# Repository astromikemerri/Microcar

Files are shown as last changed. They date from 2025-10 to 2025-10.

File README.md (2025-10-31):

# Microcar
Project for a tiny remote-control car, driven using linear actuators via a magnet, using phone as steering wheel and accelerator.  Really just having fun with some simple electronics, a 3D printer and ChatGPT to do most of the coding.  



And <A href=https://github.com/astromikemerri/Microcar/blob/main/Testdrive.mov>here is a longer test drive demo</a> to show the full silliness of the project.

In addition to standard accessories like a half-size breadboard and plenty of jumper wires, the hardware that you need, together with some suggested links for buying it, is:
<table>
  <thead> 
    <tr>
      <th>#</th>
      <th>Component</th>
      <th>Quantity</th>
      <th>Description</th>
      <th>Link</th>
    </tr>
  </thead>
  <tbody>
    <tr>
      <td>1</td>
      <td>Seeed Studio XIAO ESP32S3</td>
      <td>1</td>
      <td>ESP32 board with built-in WiFi</td>
      <td><a href="https://www.amazon.co.uk/dp/B0BYSB66S5">link</a></td>
    </tr>
    <tr>
      <td>2</td>
      <td>A4988 Stepper Driver Modules</td>
      <td>2</td>
      <td>driver boards for bipolar stepper control</td>
      <td><a href="https://www.amazon.co.uk/dp/B083V59HTB">link</a></td>
    </tr>
    <tr>
      <td>3</td>
      <td>Lead-screw Linear Actuators</td>
      <td>2</td>
      <td>Miniature 2-phase steppers with 0.5 mm lead screws and 80mm stroke</td>
      <td><a href="https://www.aliexpress.com/item/1005006040414647.html">link</a></td>
    </tr>
    <tr>
      <td>4</td>
      <td>End-stop Microswitches</td>
      <td>2</td>
      <td>Normally-open switches for homing (LOW when pressed)</td>
      <td><a href="https://www.switchelectronics.co.uk/products/11mm-lever-subminiature-pcb-microswitch-spdt-3a">link</a></td>
    </tr>
    <tr>
      <td>5</td>
      <td>9 V DC Power Supply</td>
      <td>1</td>
      <td>Regulated wall adapter for motor drivers (≥ 1 A recommended)</td>
      <td><a href="https://www.amazon.co.uk/dp/B0DF2LGSHR">link</a></td>
    </tr>
    <tr>
      <td>6</td>
      <td>Multimeter</td>
      <td>1</td>
      <td>Only needed to set the reference voltage on the A4988 boards</td>
      <td><a href="https://www.amazon.co.uk/AstroAI-Digital-Multimeter-Measurement-Electronic/dp/B01ISAMUA6/">link</a></td>
    </tr>
    <tr>
      <td>7</td>
      <td>220 micro Farad Capacitor</td>
      <td>2</td>
      <td>placed across motor power supply input on A4988, to suppress  spikes</td>
      <td><a href="https://www.amazon.co.uk/dp/B07KC99W2K">link</a></td>
    </tr>    
    <tr>
      <td>8</td>
      <td>100k Ohm Resistor</td>
      <td>2</td>
      <td>pulldown on STEP pin of A4988</td>
      <td><a href="https://www.amazon.co.uk/BOJACK-Values-Resistor-Resistors-Assortment/dp/B08FD1XVL6">link</a></td>
    </tr>    
    <tr>
      <td>9</td>
      <td>M2.5x6 screws and washers</td>
      <td>4</td>
      <td>for attaching rails to motor carriages</td>
      <td><a href="https://www.amazon.co.uk/dp/B0CNVP5P4C">link</a></td>
    </tr>    
    <tr>
      <td>10</td>
      <td>1.5mm diameter steel rods</td>
      <td>4</td>
      <td>to use as rails to drive the puck</td>
      <td><a href="https://www.amazon.co.uk/dp/B0D2V6WVT4">link</a></td>
    </tr><tr>
      <td>11</td>
      <td>5mm and 3mm diameter neodymium disc magnets</td>
      <td>1</td>
      <td>to embed in puck and car, to couple them together through the driving surface</td>
      <td><a href="https://www.amazon.co.uk/dp/B0F138V5N9">link</a></td>
    </tr>
    <tr>
      <td>12</td>
      <td>Tube of SuperLube</td>
      <td>1</td>
      <td>for greasing the rails to make sure everything moves smoothly</td>
      <td><a href="https://www.amazon.co.uk/dp/B007UU9JMS">link</a></td>
    </tr>
  </tbody>
</table>

The electronics, though it looks a bit messy, is not that complicated, essentially just connecting the  two A4988 stepper motor drivers to the Seeed XIAO ESP32S3 to control the two linear actuators.  The only other electronic hardware is the two microswitches that are attached to the ends of the stepper motor rails, which the software uses to home the two motors, so it knows where the carriages are located on their screw drives.

The pin assignments I used were:
<!-- Stepper Driver Connections -->
<table>
  <thead>
    <tr>
      <th>Axis</th>
      <th>Function</th>
      <th>ESP32 GPIO</th>
      <th>A4988 Pin</th>
      <th>Notes</th>
    </tr>
  </thead>
  <tbody>
    <tr>
      <td>X</td>
      <td>STEP</td>
      <td>GPIO 1</td>
      <td>STEP</td>
      <td>Step pulse</td>
    </tr>
    <tr>
      <td>X</td>
      <td>DIR</td>
      <td>GPIO 2</td>
      <td>DIR</td>
      <td>LOW = forward (as defined in code)</td>
    </tr>
    <tr>
      <td>X</td>
      <td>ENABLE</td>
      <td>GPIO 3</td>
      <td>EN</td>
      <td>Active LOW (LOW = driver enabled)</td>
    </tr>
    <tr>
      <td>Y</td>
      <td>STEP</td>
      <td>GPIO 9</td>
      <td>STEP</td>
      <td>Step pulse</td>
    </tr>
    <tr>
      <td>Y</td>
      <td>DIR</td>
      <td>GPIO 8</td>
      <td>DIR</td>
      <td>LOW = forward (as defined in code)</td>
    </tr>
    <tr>
      <td>Y</td>
      <td>ENABLE</td>
      <td>GPIO 7</td>
      <td>EN</td>
      <td>Active LOW (LOW = driver enabled)</td>
    </tr>
  </tbody>
</table>

<!-- Endstop Switches -->
<table>
  <thead>
    <tr>
      <th>Axis</th>
      <th>Endstop Input</th>
      <th>ESP32 GPIO</th>
      <th>Electrical</th>
      <th>Notes</th>
    </tr>
  </thead>
  <tbody>
    <tr>
      <td>X</td>
      <td>Endstop</td>
      <td>GPIO 4</td>
      <td>INPUT_PULLUP</td>
      <td>Normally-open to GND; reads LOW when pressed</td>
    </tr>
    <tr>
      <td>Y</td>
      <td>Endstop</td>
      <td>GPIO 44</td>
      <td>INPUT_PULLUP</td>
      <td>Normally-open to GND; reads LOW when pressed</td>
    </tr>
  </tbody>
</table>

The breadboard is set up to provide a 3.3V logic bus down one side, and a 9V motor driver bus down the other. As the wiring diagram shows, in addition to connecting to the ESP32 logic pins and motors, various pins on the A4988 motor driver boards are held high or low to configure the driver. The discrete components of pull-down resistors and smoothing capacitors are also placed as shown.

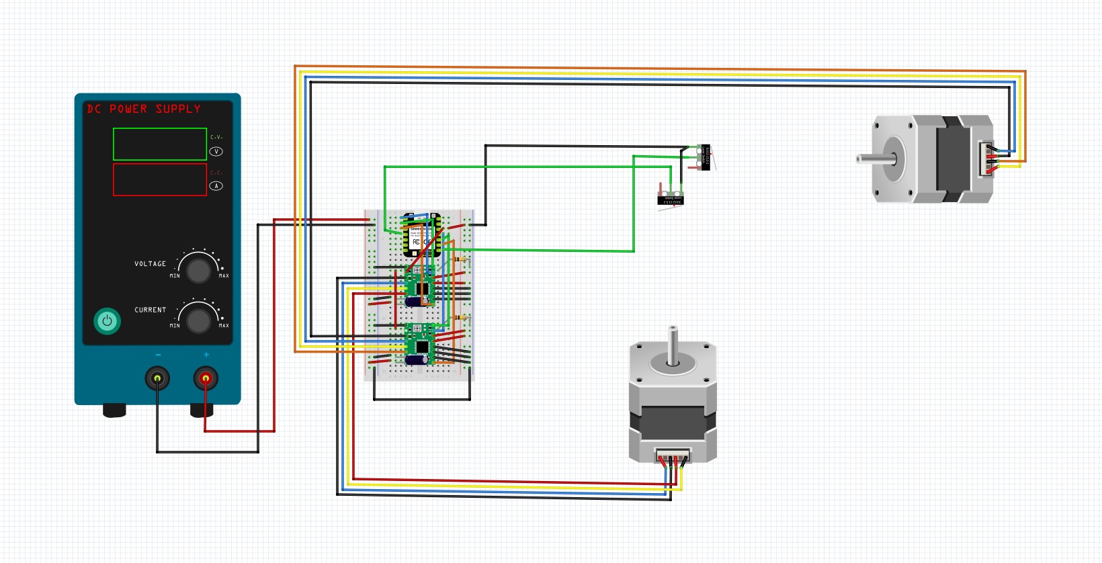
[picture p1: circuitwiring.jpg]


A Fritzing file for this wiring is <A href=https://github.com/astromikemerri/Microcar/blob/main/microcar.fzz>here</a>.

One small piece of electronic tuning you will have to do is to make sure that the A4988s have been set to a current limit appropriate to these mini stepper motors, by adjusting the potentiometers on the A4988 boards with a small screwdriver:
1. Power the setup (XIAO on, 9V power supply on).
2. connect voltmeter black to GND, red on the metal top of the pot.
3. Turn the pot slowly until you read a target voltage of approximately 0.24 V.
4. Let it sit 1–2 minutes; if the chip is too hot to touch, turn the voltage down a little.

The other hardware elements are the 3D-printed parts, <A href=https://github.com/astromikemerri/Microcar/blob/main/MotorFittings.3mf>the fittings for the motors</a> and <A href=https://github.com/astromikemerri/Microcar/blob/main/housing.3mf>the housing for the project</a>, not forgetting <A href=https://github.com/astromikemerri/Microcar/blob/main/minicar3mm.3mf>the car itself</a>. I printed these all on a Bambu A1-Mini in PETG, using 0.08mm layers, but there is nothing particularly machine-dependent in the files. 

Superglue one of your 5mm magnets into the puck and a 3mm one into the car, making sure that they are oriented to attract each other.  Slot the microswitch holders over the ends of the linear actuators, and then slide the microswitches themselves over the two pegs.  Screw the rail holders into the carriages of the two actuators. Cut the rails to 104mm, and thread them through the puck and into the rail holders attached to the carriages.  Put the little cube rail ends onto the other end of the rails. Insert the actuators into the tabs in the base.  Once all this is done, the completed hardware should look like this, ready to have the driving surface installed: 



Finally, there is <A href=https://github.com/astromikemerri/Microcar/blob/main/ignition_drive.ino>the code</a>, almost entirely courtesy of ChatGPT.  This sketch sets up the ESP32 as a web server, which serves a webpage to your phone, which uses JavaScript to access the orientation data your phone maintains, which is then sent back to the ESP32 from your phone via websockets, to control the car by driving the linear actuators.  Since iPhones only allow access to this data over a secure connection, you will also need <A href=https://github.com/astromikemerri/Microcar/blob/main/certs.h>this header file</a> with the necessary security certificates in it, which you just have to place in the same folder as the sketch when uploading the code to the ESP32 using the Arduino IDE.

Grease the rails, and now you should be good to go!  Try it a few times without the top on the housing, just to make sure everything is working.  Switch on the motor power supply then plug in the ESP32.  The actuators should home to their microswitches, and then centre in the middle of the play area.  Connect your phone to wifi server "ESP32-Tilt" (password "tilt12345"), then open web page 192.168.4.1, which should give you a link to follow to the secure server page.  When the controller web page loads, press the button to activate the tilt angles, and accept the dialog saying it is OK to activate them. Press the ignition button to start the car moving.  Hold the phone in landscape mode in your hands; tipping left and right steers, and tipping away/toward you accelerates and decelerates.  If you need to stop in a hurry, press the ignition button again. Happy driving! 

And, as a bonus, here is a 3D print file for <A href="https://github.com/astromikemerri/Microcar/blob/main/cones.3mf">those tiny traffic cones</a>.

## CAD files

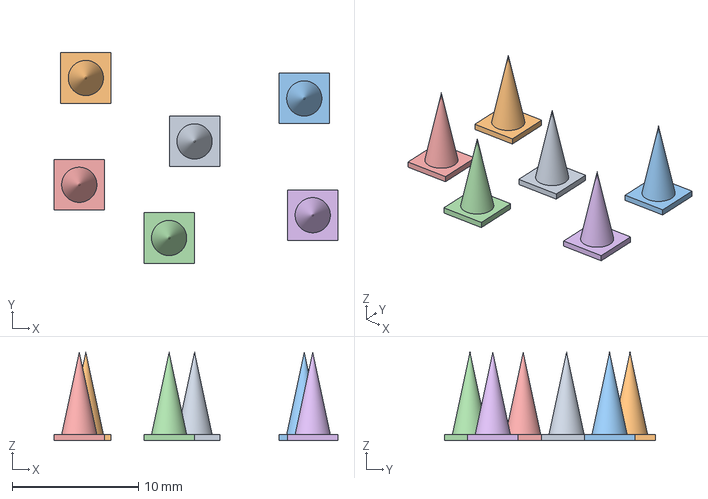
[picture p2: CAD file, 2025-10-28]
cones.3mf
22.5 x 16.7 x 7.00 mm
Assembly x 6

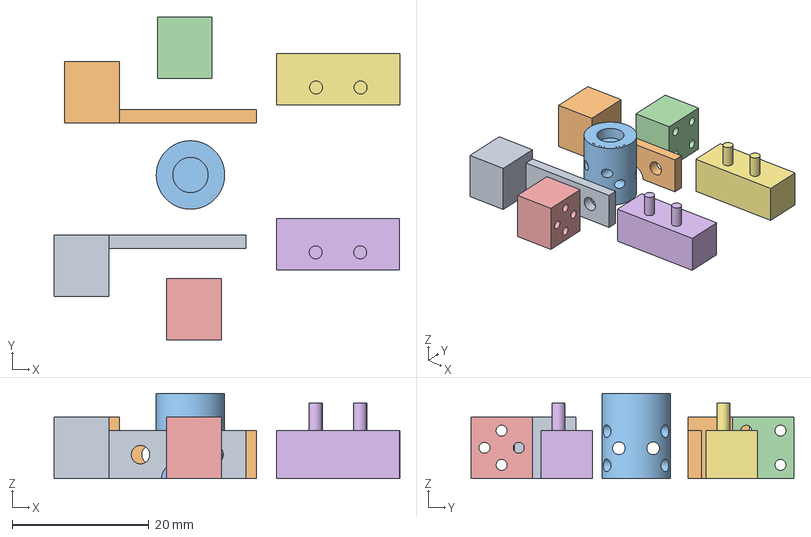
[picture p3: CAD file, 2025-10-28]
MotorFittings.3mf
50.5 x 47.2 x 12.4 mm
Carriagerailconnxtor.stl
quadCarriagerailconnxtor.stl
quadpuck.stl
quadrailendblock.stl
railendblock.stl
microswitchholder.stl x 2

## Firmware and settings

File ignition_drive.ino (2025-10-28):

#include <Arduino.h>
#include <WiFi.h>
#include <pgmspace.h>
#include <math.h>
#include <esp_https_server.h>
#include <esp_http_server.h>

#include "certs.h"  // your PEMs

/******** Geometry & timing ********/
#ifndef TRACK_LEN_MM
#define TRACK_LEN_MM   75
#endif
const float SOFT_MIN_MM = 0.0f;
const float SOFT_MAX_MM = (float)TRACK_LEN_MM;

const int   STEPS_PER_REV   = 20;
const float LEAD_MM_PER_REV = 0.5f;
const int   STEPS_PER_MM    = STEPS_PER_REV / LEAD_MM_PER_REV;   // 40

const int STEP_HIGH_US = 60;
const int MIN_DWELL_US = 600;

const int HOMING_DELAY_US = 1000;
const int SAFE_START_MM   = 10;
const int MAX_HOME_MM     = 100;
const long MAX_HOME_STEPS = (long)MAX_HOME_MM * STEPS_PER_MM;

const int   CENTER_DWELL_US = 1200;
const float LAND_MARGIN      = 0.3f;

static inline uint32_t max_u32(uint32_t a, uint32_t b){ return a>b?a:b; }

/******** Motion layer ********/
class StepperAxis {
public:
  StepperAxis(int stepPin,int dirPin,int enPin,int endPin,int forwardDirLevel,const char* name)
  : STEP(stepPin),DIR(dirPin),EN(enPin),ES(endPin),
    FWD(forwardDirLevel),REV(forwardDirLevel==HIGH?LOW:HIGH),label(name){}
  void begin(){ pinMode(STEP,OUTPUT); pinMode(DIR,OUTPUT); pinMode(EN,OUTPUT); pinMode(ES,INPUT_PULLUP);
    digitalWrite(EN,HIGH); digitalWrite(STEP,LOW); delay(50); enable(); }
  void enable(){ digitalWrite(EN,LOW); }
  void setDirection(bool fwd){ digitalWrite(DIR,fwd?FWD:REV); }
  float mm() const { return (float)posSteps/(float)STEPS_PER_MM; }
  void pulseFast(){ digitalWrite(STEP,HIGH); delayMicroseconds(STEP_HIGH_US); digitalWrite(STEP,LOW); delayMicroseconds(STEP_HIGH_US); }
  bool stepForward(){ if(posSteps >= (long)(SOFT_MAX_MM*STEPS_PER_MM)) return false; setDirection(true); pulseFast(); posSteps++; return true; }
  bool stepReverse(){ if(posSteps <= (long)(SOFT_MIN_MM*STEPS_PER_MM)) return false; setDirection(false); pulseFast(); posSteps--; return true; }
  void moveMM(float dmm){ if(!dmm) return; long n = lroundf(fabsf(dmm)*STEPS_PER_MM); bool fwd=dmm>0;
    for(long i=0;i<n;i++){ if(fwd){ if(!stepForward()) break; } else { if(!stepReverse()) break; } delayMicroseconds(150);} }
  void moveToMM(float t){ moveMM(t - mm()); }
  bool home(){
    if(endstopPressed()){ int guard=3*STEPS_PER_MM; while(endstopPressed()&&guard-->0){ setDirection(true); pulseFast(); posSteps++; delayMicroseconds(900);} delay(30);}
    setDirection(false); long cnt=0; while(!endstopPressed()){ pulseFast(); posSteps--; delayMicroseconds(HOMING_DELAY_US);
      if(++cnt>MAX_HOME_STEPS){ Serial.printf("[%s] Home guard hit\n",label); return false; } }
    setDirection(true); { int guard=3*STEPS_PER_MM; while(endstopPressed()&&guard-->0){ pulseFast(); posSteps++; delayMicroseconds(900); }
      int extra=(int)(0.5f*STEPS_PER_MM); for(int i=0;i<extra;i++){ pulseFast(); posSteps++; delayMicroseconds(900);} }
    posSteps=0; Serial.printf("[%s] Home=0mm\n",label); return true;
  }
  void moveToMM_slow(float tgt,int dwell_us=CENTER_DWELL_US){
    if(tgt<SOFT_MIN_MM) tgt=SOFT_MIN_MM; if(tgt>SOFT_MAX_MM) tgt=SOFT_MAX_MM; long T=lroundf(tgt*STEPS_PER_MM);
    bool fwd = (T>posSteps); setDirection(fwd); long N=labs(T-posSteps);
    for(long i=0;i<N;i++){ pulseFast(); posSteps+= fwd?1:-1; delayMicroseconds(dwell_us); }
  }
private:
  const int STEP,DIR,EN,ES; const int FWD,REV; const char* label; long posSteps=0;
  bool endstopPressed(){ const int N=5; int c=0; for(int i=0;i<N;i++){ if(digitalRead(ES)==LOW) c++; delay(1);} return c>N/2; }
};

// Pins (adjust if needed)
StepperAxis axisX(1,2,3,4,LOW,"X");
StepperAxis axisY(9,8,7,44,LOW,"Y");

// Coordinator
struct Coordinator {
  float rx_steps=0.0f, ry_steps=0.0f;
  void moveVectorMM(float dx,float dy,uint32_t dt_ms){
    float x0=axisX.mm(), y0=axisY.mm();
    float xt=constrain(x0+dx,SOFT_MIN_MM,SOFT_MAX_MM);
    float yt=constrain(y0+dy,SOFT_MIN_MM,SOFT_MAX_MM);
    dx=xt-x0; dy=yt-y0;
    float sx_f = dx*STEPS_PER_MM + rx_steps;
    float sy_f = dy*STEPS_PER_MM + ry_steps;
    long stepsX=lroundf(fabsf(sx_f)), stepsY=lroundf(fabsf(sy_f));
    if(stepsX==0 && stepsY==0){ rx_steps=sx_f; ry_steps=sy_f; delay(dt_ms); return; }
    long N = (stepsX>stepsY)?stepsX:stepsY;
    bool xf=(sx_f>=0), yf=(sy_f>=0); axisX.setDirection(xf); axisY.setDirection(yf);
    float incx=(stepsX>0)?(float)stepsX/(float)N:0.0f, incy=(stepsY>0)?(float)stepsY/(float)N:0.0f;
    float ex=0.0f, ey=0.0f;
    uint32_t per = (N>0)? max_u32((uint32_t)MIN_DWELL_US, (uint32_t)((dt_ms*1000UL)/(uint32_t)N)) : (uint32_t)MIN_DWELL_US;
    for(long i=0;i<N;i++){
      ex+=incx; if(ex>=1.0f){ ex-=1.0f; if(xf) (void)axisX.stepForward(); else (void)axisX.stepReverse(); }
      ey+=incy; if(ey>=1.0f){ ey-=1.0f; if(yf) (void)axisY.stepForward(); else (void)axisY.stepReverse(); }
      delayMicroseconds(per);
    }
    float x1=axisX.mm(), y1=axisY.mm();
    float ax=(x1-x0)*STEPS_PER_MM, ay=(y1-y0)*STEPS_PER_MM;
    rx_steps = sx_f - ax; ry_steps = sy_f - ay;
  }
  void movePolar(float v_mm_s, float theta_rad, uint32_t dt_ms){
    float dt_s=dt_ms/1000.0f;
    moveVectorMM(v_mm_s*cosf(theta_rad)*dt_s, v_mm_s*sinf(theta_rad)*dt_s, dt_ms);
  }
  void resetResiduals(){ rx_steps=0.0f; ry_steps=0.0f; }
} ctrl;

/******** Centering helpers ********/
void lineToXY_slow(float x,float y,int dwell_us=CENTER_DWELL_US){
  x=constrain(x,SOFT_MIN_MM,SOFT_MAX_MM); y=constrain(y,SOFT_MIN_MM,SOFT_MAX_MM);
  float x0=axisX.mm(), y0=axisY.mm(); float dx=x-x0, dy=y-y0;
  long sx=lroundf(dx*STEPS_PER_MM), sy=lroundf(dy*STEPS_PER_MM);
  long ax=labs(sx), ay=labs(sy), N=(ax>ay)?ax:ay; if(!N) return;
  bool xf=(sx>=0), yf=(sy>=0); float ex=0, ey=0, incx=(ax>0)?(float)ax/N:0, incy=(ay>0)?(float)ay/N:0;
  axisX.setDirection(xf); axisY.setDirection(yf);
  for(long i=0;i<N;i++){
    ex+=incx; if(ex>=1.0f){ ex-=1.0f; if(xf) (void)axisX.stepForward(); else (void)axisX.stepReverse(); }
    ey+=incy; if(ey>=1.0f){ ey-=1.0f; if(yf) (void)axisY.stepForward(); else (void)axisY.stepReverse(); }
    delayMicroseconds(dwell_us);
  }
}
void centerAxesReliably(float center_mm = TRACK_LEN_MM * 0.5f){
  axisX.enable(); axisY.enable();
  const float SEAT_MM=5.0f;
  axisX.moveToMM_slow(min(SOFT_MAX_MM-LAND_MARGIN, axisX.mm()+SEAT_MM));
  axisY.moveToMM_slow(min(SOFT_MAX_MM-LAND_MARGIN, axisY.mm()+SEAT_MM));
  const float FAR = SOFT_MAX_MM - LAND_MARGIN;
  axisX.moveToMM_slow(FAR); axisY.moveToMM_slow(FAR);
  lineToXY_slow(center_mm, center_mm);
  axisX.moveToMM_slow(center_mm); axisY.moveToMM_slow(center_mm);
}

/******** Tilt mapping ********/
volatile float lastGamma = NAN, lastBeta = NAN;
volatile bool  gotData   = false;
volatile bool  ignition_on = false;   // NEW ignition flag

volatile float theta_cmd = 0.0f;  // rad
volatile float v_mm_s    = 0.0f;  // mm/s

#ifndef MAX_TURN_RATE
#define MAX_TURN_RATE    0.8f
#endif
#ifndef MAX_ACCEL
#define MAX_ACCEL        8.0f
#endif
#ifndef MAX_DECEL
#define MAX_DECEL        8.0f
#endif
#ifndef V_MAX
#define V_MAX            15.0f
#endif
#ifndef V_MIN
#define V_MIN            0.0f
#endif
#ifndef BETA_DEADBAND
#define BETA_DEADBAND    2.0f
#endif
#ifndef GAMMA_DEADBAND
#define GAMMA_DEADBAND   2.0f
#endif

static const float BETA_MIN=-40.0f,BETA_MAX=40.0f, GAMMA_MIN=-70.0f,GAMMA_MAX=-30.0f;

static inline float clampf(float v,float lo,float hi){ return v<lo?lo:(v>hi?hi:v); }
static float fmap_clamped(float x,float in_min,float in_max,float out_min,float out_max){
  if(x<=in_min) return out_min; if(x>=in_max) return out_max;
  float t=(x-in_min)/(in_max-in_min); return out_min + t*(out_max-out_min);
}
static float apply_deadband_symmetric(float x,float db,float in_min,float in_max){
  if(fabsf(x)<=db) return 0.0f;
  if(x>0){ float span=in_max-db; return (x-db)*(in_max/span); }
  float span=in_min+db; return (x+db)*(in_min/span);
}
static void tiltToRates_mm(float beta,float gamma,float &dtheta_dt,float &dv_dt){
  float beta_db=apply_deadband_symmetric(beta,BETA_DEADBAND,BETA_MIN,BETA_MAX);
  dtheta_dt=fmap_clamped(beta_db,BETA_MIN,BETA_MAX,-MAX_TURN_RATE,+MAX_TURN_RATE);
  if(fabsf(gamma+50.0f)<=GAMMA_DEADBAND) gamma=-50.0f;
  dv_dt=fmap_clamped(gamma,GAMMA_MIN,GAMMA_MAX,-MAX_DECEL,+MAX_ACCEL);
}

/******** HTTPS + WSS ********/
static const char* AP_SSID="ESP32-Tilt";
static const char* AP_PASS="tilt12345";

static const char INDEX_HTML[] PROGMEM = R"HTML(
<!doctype html><meta charset="utf-8">
<meta name="viewport" content="width=device-width,initial-scale=1">
<title>ESP32 Tilt (WSS)</title>
<style>
:root{color-scheme:light dark}
body{font-family:system-ui,-apple-system,Segoe UI,Roboto,Helvetica,Arial,sans-serif;margin:2rem}
.card{max-width:560px;padding:1rem;border:1px solid #ddd;border-radius:12px;box-shadow:0 2px 12px rgba(0,0,0,.06)}
button{padding:.6rem 1rem;border:0;border-radius:10px;cursor:pointer;margin-right:.5rem}
#ign{background:#c62828;color:#fff}
#ign.on{background:#2e7d32}
.mono{font-family:ui-monospace,Consolas,Monaco,monospace}
</style>
<div class="card">
  <h1>Phone Tilt → ESP32 (HTTPS + WSS)</h1>
  <p>Status: <span id="ws">disconnected</span></p>
  <p class="mono">γ: <span id="g">–</span>° &nbsp; β: <span id="b">–</span>°</p>
  <p>
    <button id="perm">Start sensors</button>
    <button id="ign" class="">Ignition: OFF</button>
  </p>
  <p style="margin-top:.5rem;font-size:.9rem;opacity:.75">iOS needs HTTPS and a user gesture. Accept the certificate if prompted.</p>
</div>
<script>
let ws, latest={g:NaN,b:NaN}, ignition=0;
function connectWS(){
  ws = new WebSocket(`wss://${location.hostname}:8443/ws`);
  const el = document.getElementById('ws');
  ws.onopen  = ()=> el.textContent='connected';
  ws.onclose = ()=> el.textContent='disconnected';
  ws.onerror = ()=> el.textContent='error';
}
async function ensurePerm(){
  try{
    if(typeof DeviceMotionEvent!=='undefined' && typeof DeviceMotionEvent.requestPermission==='function'){
      return (await DeviceMotionEvent.requestPermission())==='granted';
    }else if(typeof DeviceOrientationEvent!=='undefined' && typeof DeviceOrientationEvent.requestPermission==='function'){
      return (await DeviceOrientationEvent.requestPermission())==='granted';
    }
    return true;
  }catch(e){return false;}
}
function startSensors(){
  window.addEventListener('deviceorientation', e=>{
    latest.g = (typeof e.gamma==='number')?e.gamma:NaN;
    latest.b = (typeof e.beta ==='number')?e.beta :NaN;
    document.getElementById('g').textContent = Number.isFinite(latest.g)?latest.g.toFixed(2):'NaN';
    document.getElementById('b').textContent = Number.isFinite(latest.b)?latest.b.toFixed(2):'NaN';
  }, true);
  setInterval(()=>{
    if(ws && ws.readyState===1 && Number.isFinite(latest.g) && Number.isFinite(latest.b)){
      ws.send(`g:${latest.g.toFixed(4)},b:${latest.b.toFixed(4)},ign:${ignition}`);
    }
  }, 50);
}
document.getElementById('perm').addEventListener('click', async ()=>{
  if(!(await ensurePerm())){ alert('Motion permission denied.'); return; }
  if(!ws || ws.readyState!==1) connectWS();
  startSensors();
});
document.getElementById('ign').addEventListener('click', ()=>{
  ignition = ignition ? 0 : 1;
  const btn = document.getElementById('ign');
  if(ignition){ btn.textContent='Ignition: ON'; btn.classList.add('on'); }
  else        { btn.textContent='Ignition: OFF'; btn.classList.remove('on'); }
  // Send an immediate state update
  if(ws && ws.readyState===1){
    const g = Number.isFinite(latest.g)?latest.g.toFixed(4):'NaN';
    const b = Number.isFinite(latest.b)?latest.b.toFixed(4):'NaN';
    ws.send(`g:${g},b:${b},ign:${ignition}`);
  }
});
</script>
)HTML";

httpd_handle_t srv_https=nullptr, srv_http=nullptr;

static esp_err_t index_get_handler(httpd_req_t *req){
  httpd_resp_set_type(req,"text/html");
  httpd_resp_set_hdr(req,"Cache-Control","no-store");
  httpd_resp_send(req, INDEX_HTML, HTTPD_RESP_USE_STRLEN);
  return ESP_OK;
}
static esp_err_t ws_handler(httpd_req_t *req){
  if(req->method==HTTP_GET) return ESP_OK;
  httpd_ws_frame_t f={}; f.type=HTTPD_WS_TYPE_TEXT;
  if(httpd_ws_recv_frame(req,&f,0)!=ESP_OK) return ESP_FAIL;
  if(f.len>4096) return ESP_FAIL;
  uint8_t* payload=(uint8_t*)malloc(f.len+1); if(!payload) return ESP_ERR_NO_MEM;
  f.payload=payload;
  if(httpd_ws_recv_frame(req,&f,f.len)!=ESP_OK){ free(payload); return ESP_FAIL; }
  payload[f.len]=0;
  const char* c=(const char*)payload;
  const char* gpos=strstr(c,"g:"); const char* bpos=strstr(c,"b:"); const char* ipos=strstr(c,"ign:");
  if(gpos && bpos){
    float g=strtof(gpos+2,nullptr); float b=strtof(bpos+2,nullptr);
    if(isfinite(g)&&isfinite(b)){ lastGamma=g; lastBeta=b; gotData=true; }
  }
  if(ipos){
    int ign = strtol(ipos+4,nullptr,10);
    ignition_on = (ign!=0);
  }
  free(payload);
  return ESP_OK;
}
static esp_err_t http80_index(httpd_req_t *req){
  httpd_resp_set_type(req,"text/html");
  IPAddress ip=WiFi.softAPIP();
  String body=String("<!doctype html><meta charset='utf-8'><title>ESP32 tilt – HTTP</title><h1>ESP32 running</h1><p>Open <a href='https://")
              + ip.toString() + ":8443/'>https://" + ip.toString() + ":8443/</a></p>";
  httpd_resp_send(req, body.c_str(), body.length());
  return ESP_OK;
}
void start_http_helper(){
  httpd_config_t cfg=HTTPD_DEFAULT_CONFIG();
  cfg.server_port=80; cfg.lru_purge_enable=true;
  if(httpd_start(&srv_http,&cfg)==ESP_OK){
    httpd_uri_t root={}; root.uri="/"; root.method=HTTP_GET; root.handler=http80_index;
    httpd_register_uri_handler(srv_http,&root);
    Serial.println("[HTTP] helper up on :80");
  }
}
bool start_https_wss_server_8443(){
  const unsigned char* cert_ptr=(const unsigned char*)SERVER_CERT_PEM;
  const unsigned char* key_ptr =(const unsigned char*)SERVER_KEY_PEM;
  size_t cert_len=strlen_P((PGM_P)SERVER_CERT_PEM)+1;
  size_t key_len =strlen_P((PGM_P)SERVER_KEY_PEM)+1;
  httpd_ssl_config_t conf=HTTPD_SSL_CONFIG_DEFAULT();
  conf.port_secure=8443; conf.transport_mode=HTTPD_SSL_TRANSPORT_SECURE;
  conf.servercert=cert_ptr; conf.servercert_len=cert_len;
  conf.prvtkey_pem=key_ptr; conf.prvtkey_len=key_len;
  conf.httpd.stack_size=12288; conf.httpd.max_open_sockets=4;
  conf.httpd.lru_purge_enable=true; conf.httpd.recv_wait_timeout=10; conf.httpd.send_wait_timeout=10;
  if(httpd_ssl_start(&srv_https,&conf)!=ESP_OK){ Serial.println("[HTTPS] start failed"); return false; }
  httpd_uri_t root={}; root.uri="/"; root.method=HTTP_GET; root.handler=index_get_handler; httpd_register_uri_handler(srv_https,&root);
  httpd_uri_t ws={}; ws.uri="/ws"; ws.method=HTTP_GET; ws.handler=ws_handler; ws.is_websocket=true; ws.handle_ws_control_frames=true;
  httpd_register_uri_handler(srv_https,&ws);
  Serial.println("[HTTPS/WSS] listening on :8443 (/, /ws)");
  return true;
}

/******** Setup / Loop (velocity mode) ********/
unsigned long lastPrintMs=0, lastPhysUpdateMs=0, lastCmdMs=0;
static const uint32_t CMD_PERIOD_MS = 80;

void setup(){
  Serial.begin(115200); delay(200);
  WiFi.mode(WIFI_AP); WiFi.softAP(AP_SSID,AP_PASS); WiFi.setSleep(false);
  IPAddress ip=WiFi.softAPIP();
  Serial.printf("[WiFi] AP up. http://%s  →  https://%s:8443/\n", ip.toString().c_str(), ip.toString().c_str());
  start_https_wss_server_8443(); start_http_helper();

  axisX.begin(); axisY.begin();
  axisX.moveMM(+SAFE_START_MM); axisY.moveMM(+SAFE_START_MM);
  bool okX=axisX.home(), okY=axisY.home(); if(!(okX&&okY)) Serial.println("Homing failed — check wiring/dir/switch.");
  centerAxesReliably(TRACK_LEN_MM * 0.5f);

  lastPhysUpdateMs = lastCmdMs = millis();
}

void loop(){
  unsigned long now=millis();
  if(lastPhysUpdateMs==0) lastPhysUpdateMs=now;
  float dt=(now - lastPhysUpdateMs)/1000.0f; lastPhysUpdateMs=now;

  float dtheta_dt=0.0f, dv_dt=0.0f;
  if(gotData && isfinite(lastBeta) && isfinite(lastGamma)){
    float beta = clampf(lastBeta,  -40.0f, +40.0f);
    float gamma= clampf(lastGamma, -70.0f, -30.0f);
    tiltToRates_mm(beta, gamma, dtheta_dt, dv_dt);
  }

  // Steering can still change; speed is locked to 0 when ignition is OFF
  theta_cmd += dtheta_dt * dt;
  if(theta_cmd >  PI) theta_cmd -= 2.0f*PI;
  if(theta_cmd < -PI) theta_cmd += 2.0f*PI;

  if(ignition_on){
    v_mm_s += dv_dt * dt;
    v_mm_s  = clampf(v_mm_s, V_MIN, V_MAX);
  }else{
    v_mm_s = 0.0f;    // hold still when ignition OFF
  }

  if(now - lastCmdMs >= CMD_PERIOD_MS){
    lastCmdMs = now;
    ctrl.movePolar(v_mm_s, theta_cmd, CMD_PERIOD_MS);
  }

  if(now - lastPrintMs >= 1000){
    lastPrintMs = now;
    float px=axisX.mm(), py=axisY.mm();
    Serial.printf("IGN=%d | β=%.1f° γ=%.1f° | θ=%.2f rad  v=%.2f mm/s | pos=(%.1f, %.1f) mm\n",
                  ignition_on?1:0, lastBeta, lastGamma, theta_cmd, v_mm_s, px, py);
  }
}
